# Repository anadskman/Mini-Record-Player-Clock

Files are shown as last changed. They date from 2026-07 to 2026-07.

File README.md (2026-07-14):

# Mini Record Player Clock

A compact desktop Bluetooth speaker and clock inspired by a vintage record player. The aim of this project is to combine a functional Bluetooth speaker and Wi-Fi clock into a clean, fully 3D printed desktop display. Rather than using lots of jumper wires and modules glued together, everything is connected through a custom PCB designed specifically for this project.

The record spins while music is playing, the tonearm moves using a servo, and the front display shows the current time synced over Wi-Fi. All electronics are housed inside a custom enclosure designed in Fusion 360.

## Features

- Bluetooth music playback
- Wi-Fi synced digital clock
- 2.4" ILI9341 colour TFT display
- Spinning 3D printed record
- Servo driven moving tonearm
- Physical playback buttons
- Custom PCB
- Fully 3D printed enclosure
- Powered by a 5V wall adapter

## Hardware

### Electronics

- ESP32 Dev Board
- 2.4" ILI9341 TFT Display
- PAM8403 Audio Amplifier
- 4Ω 3W Speaker
- 5V DC Motor
- SG90 Servo
- IRLZ44N MOSFET
- 1N5819 Diodes
- Push Buttons
- LEDs
- Capacitors and Resistors
- Custom PCB

### Mechanical

- Fully 3D printed enclosure
- 3D printed record
- 3D printed tonearm
- Motor mount
- Hinged lid
- PCB mounting system
- M2 hardware

## Software

The ESP32 is responsible for controlling the entire project. It handles Bluetooth audio, synchronises the clock over Wi-Fi, updates the display, controls the spinning record and tonearm, and reads the playback buttons.

The firmware is written using the Arduino framework and is designed so each part of the project works independently while sharing the same controller.

## PCB

A custom two-layer PCB was designed in KiCad to act as the hub of the project. All components connect directly to the PCB which keeps the wiring simple and makes assembly much cleaner.

Some design considerations included:

- Ground planes on both PCB layers
- Wider traces for power distribution
- Decoupling capacitors placed beside each module
- Reverse polarity protection
- Clearly labelled connectors
- Connectors for external buttons, speaker and servo
- Mounting holes for the enclosure

## CAD

The enclosure was designed in Fusion 360 around the PCB to ensure everything fits correctly.

The design includes:

- Front display opening
- Side mounted playback buttons
- Speaker openings
- Hinged top lid
- Motor mount
- Servo mount
- PCB mounting points
- Rear barrel jack opening

## BOM

| Component | Cost | Status |
|---|---:|---|
| TFT Display 2.4" ILI9341 | $4.01 | Buy |
| 4Ω 3W Speaker | $2.09 | Buy |
| Screw Terminal (7x) | Owned | Owned |
| DC Barrel Jack | Owned | Owned |
| LEDs (2x) | Owned | Owned |
| MOSFET | Owned | Owned |
| Header Pins | Owned | Owned |
| PAM8403 Amplifier Module | $4.02 | Buy |
| DC Motor | Owned | Owned |
| SG90 Servo Motor | Owned | Owned |
| 100µF Capacitors | Owned | Owned |
| 100nF Ceramic Capacitors | Owned | Owned |
| 470µF Capacitor | $8.65 | Buy |
| 10µF Capacitors | $2.13 | Buy |
| 1µF Capacitors | $2.08 | Buy |
| Resistors | Owned | Owned |
| 1N5819 Diodes | $4.35 | Buy |
| Push Buttons | Owned | Owned |
| ESP32 Dev Board | $4.40 | Buy |
| 5V 5A Barrel Jack Power Supply | $9.43 | Buy |
| PCB | $27.77 | Buy |
| M2 Screws | $5.40 | Buy |
| Pin Headers (ESP32) | $6.06 | Buy |
| Shipping | $1.63 | |
| Duties | $33.01 | |
| Total | $115.03 | |

## Images
| Schematic | PCB | CAD |
| :---: | :---: | :---: |
|  |  |  |

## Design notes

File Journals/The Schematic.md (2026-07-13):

# Schematic
***(3hr)***

I started by placing all the components *(Or their headers)*

#### ESP32
- `DEVKIT_V1_ESP32-WROOM-32`*(imported as the actual board wasnt on kicad)*

#### Power
- `DC Barrel Jack`*(I must make sure when choosing footprints I select a big enough holes for my barrel jack, my last one was too small)*
- x2 `PWR_FLAG` 
- `+5V` `GND`
- `Device:C_Polarized` *(470uF)*
- `Device:C` *(100nF)*
- `Device:C_Polarized` *(10uF)*
- `Switch:SW_SPST`
- `Diode:ss14`

#### Audio
- `Connector:Conn_01x09_Socket`
  - `Device:C` *(100nF)*
  - `Device:C_Polarized` *(10uF)*

#### Motor
- `Connector:Conn_01x02_Socket`
- `Transistor_FET:IRLZ44N`
- `Device:R` *(220R)*
- `Device:R` *(10K)*
- `1N5819`
- `Device:C_Polarized` *(100uF)*
- `Device:C` *(100nF)*

#### Speaker
- `Connector:Conn_01x02_Socket`

#### Servo
- `Connector:Conn_01x03_Pin`
- `Device:C_Polarized` *(100uF)*
- `Device:C` *(100nF)*

#### Display
- `Connector:Conn_01x14_Socket`
- x1 `Device:C` *(100nF)*
- `Device:C_Polarized` *(10uF)*

#### Buttons
- x3 `Switch:SW_Push`

#### LEDs
- x2 `Device:LED`
- x2 `Device:R` *(330R)*

#### Mounting holes
- x4 `Mechanical:MountingHole`

While I placing everything I added text to help keep everything tidy.



After I placed everything I did a quick sanity check and realised I forgot to add a few capacitors.

I started with all the power wiring first
I did wire the mosfet though, and the servo.

*(On my PCB I need to make sure my connectors line up, for e.g. gnd 5v and signal are in the correct place for servo)*



After those were wired I connected the Speaker to the audio amp, the LEDs to the esp32, and the Buttons to the esp32.

After they were connected I ran a quick ERC.



Before I moved on to the pcb I made sure everything was connected correctly, basically a sanity check, after that I also sent a Screenshot into #hardware to see if anyone spot anything wrong

Once everything seemed fine I annotated it and that was the schematic done.

I ended up change the buttons from being on the pcb, to be on the case instead so I replaced their footprints with `Connector_Generic:Conn_01x02`

I also found a symbol and footprint on github for pam8403 so i download it and replace my 01x09 connector with it.

# Footprints

After I annotated the schematic I assigned the footprints.

- `DEVKIT_V1_ESP32-WROOM-32:MODULE_DEVKIT_V1_ESP32-WROOM-32`
- `Connector_BarrelJack:BarrelJack_Horizontal` *(I measured my barrel Jack and made sure that it would fit)*
- `Connector_PinHeader_2.54mm:PinHeader_1x02_P2.54mm_Horizontal`
- `Capacitor_THT:CP_Radial_D5.0mm_P2.00mm`
- `Capacitor_THT:CP_Radial_D6.3mm_P2.50mm`
- `Capacitor_THT:CP_Radial_D8.0mm_P3.50mm`
*(I'll double check that my caps fit these footprints)*
- x2 `TerminalBlock_Phoenix:TerminalBlock_Phoenix_MPT-0,5-2-2.54_1x02_P2.54mm_Horizontal`
- `Connector_PinHeader_2.54mm:PinHeader_1x03_P2.54mm_Vertical`
- `Connector_PinHeader_2.54mm:PinHeader_1x14_P2.54mm_Vertical`
- `Package_TO_SOT_THT:TO-220-3_Vertical`
- `Resistor_THT:R_Axial_DIN0207_L6.3mm_D2.5mm_P10.16mm_Horizontal`



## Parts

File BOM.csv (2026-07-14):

Component | Cost | Status | Link
TFT Display 2.4" ILI9341 | $4.01 | Buy | https://www.aliexpress.com/item/1005006624846563.html
4Ω 3W Speaker | $2.09 | Buy | https://www.aliexpress.com/item/1005008004635189.html
Screw Terminal (7x) | Owned | Owned
DC Barrel Jack | Owned | Owned
LEDs (2x) | Owned | Owned
MOSFET | Owned | Owned
Header Pins | Owned | Owned
PAM8403 Amplifier Module | $4.02 | Buy | https://www.aliexpress.com/item/32848888092.html
DC Motor | Owned | Owned
SG90 Servo Motor | Owned | Owned
100µF Capacitors | Owned | Owned
100nF Ceramic Capacitors | Owned | Owned
470µF Capacitor | $8.65 | Buy | https://www.aliexpress.com/item/1005003808375884.html?pdp_ext_f=%7B"order"%3A"108"%2C"eval"%3A"1"%2C"fromPage"%3A"search"%7D
10µF Capacitors | $2.13 | Buy | https://www.aliexpress.com/item/1005011728628651.html
1µF Capacitors | $2.08 | Buy | https://www.aliexpress.com/item/1005011728628651.html
Resistors | Owned | Owned
1N5819 Diodes | $4.35 | Buy | https://www.aliexpress.com/item/32866531235.html
Push Buttons | Owned | Owned
ESP32 Dev Board | $4.40 | Buy | https://www.aliexpress.com/item/1005004605399313.html
5V 5A Barrel Jack Power Supply | $9.43 | Buy | https://www.aliexpress.com/item/1005009715118182.html?pdp_ext_f=%7B"order"%3A"274"%2C"eval"%3A"1"%2C"fromPage"%3A"search"%7D
PCB | $27.77 | Buy | https://jlcpcb.com
M2 Screws | $5.40 | Buy | https://www.aliexpress.com/item/1005011580506515.html?mp=1
Pin Headers (for ESP32) | $6.06 | Buy | https://www.aliexpress.com/item/1005004945845785.html?pdp_ext_f=%7B"order"%3A"238"%2C"spu_best_type"%3A"price"%2C"eval"%3A"1"%2C"fromPage"%3A"search"%7D
Shipping | $1.63 | Charge
Duties | $33.01 | Charge

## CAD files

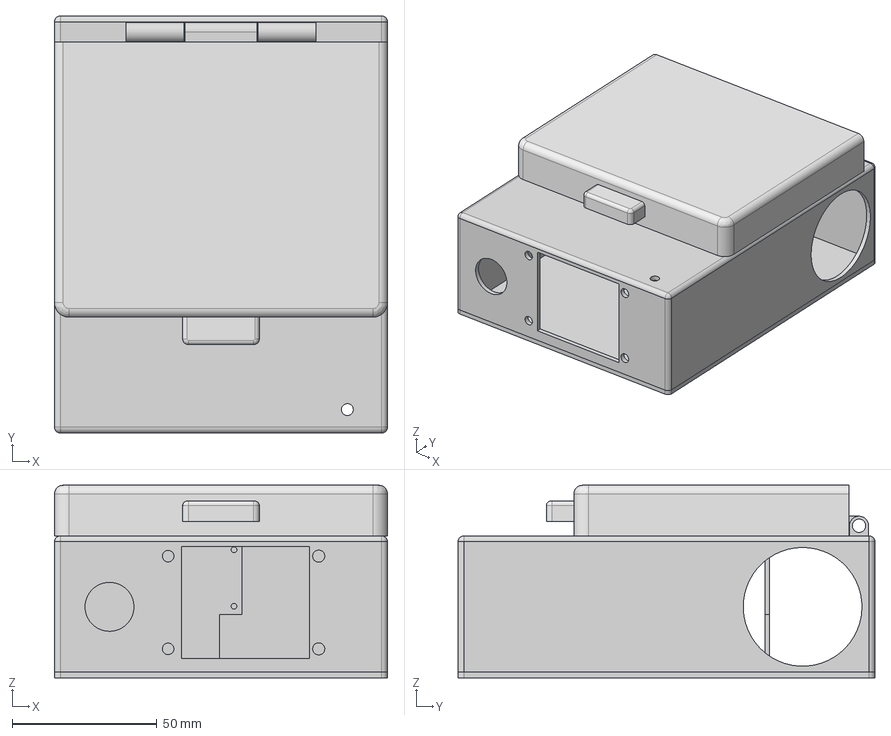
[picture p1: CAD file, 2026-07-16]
CAD/Record Player Clock - without components.step
115.0 x 144.0 x 66.5 mm
Front
Sides
Needle
Hinge
Back
Bottom

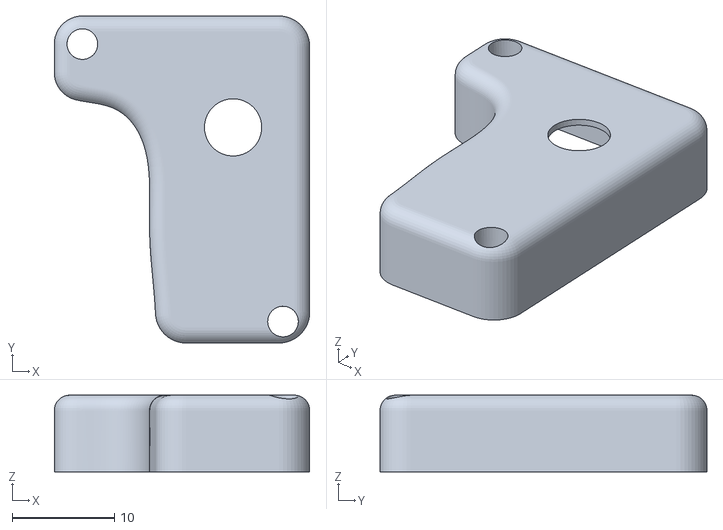
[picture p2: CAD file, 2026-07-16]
CAD/servo cover.stl
25.0 x 32.0 x 7.50

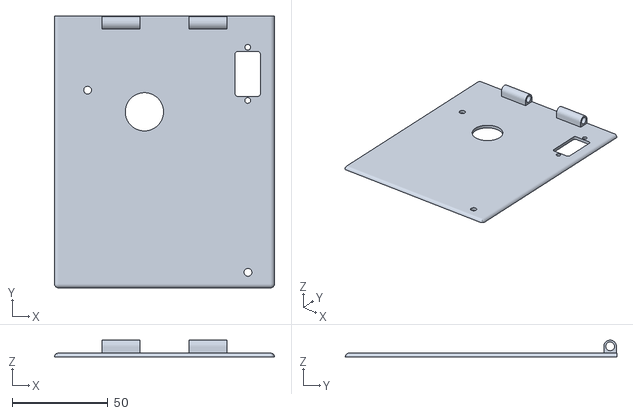
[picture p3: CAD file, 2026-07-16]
CAD/top.stl
115.0 x 142.0 x 8.80

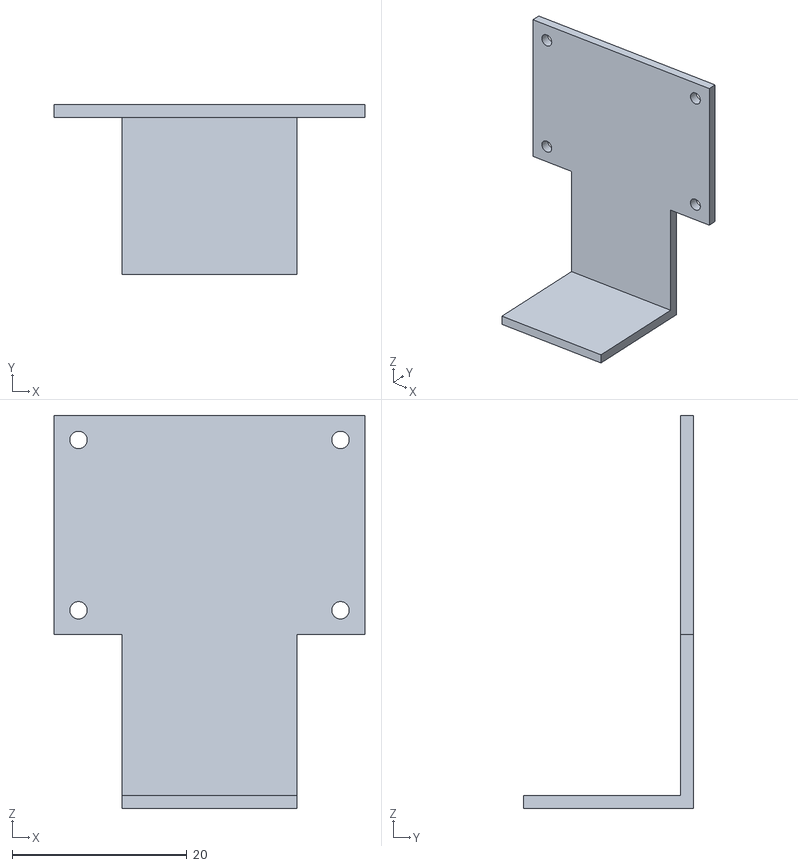
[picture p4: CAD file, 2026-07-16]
CAD/motor mount.stl
35.6 x 19.5 x 45.0

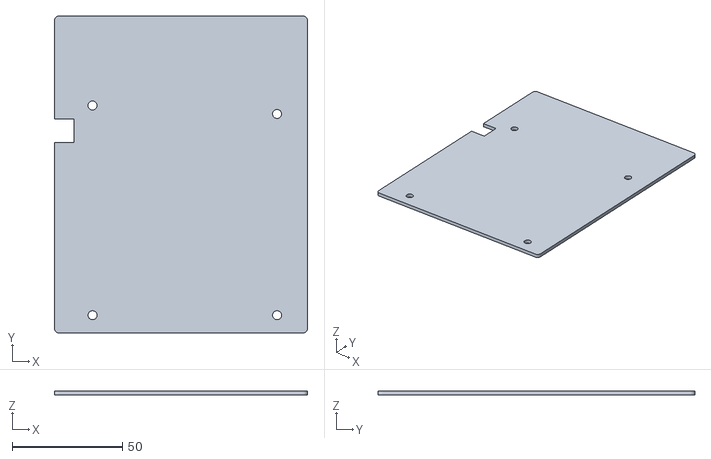
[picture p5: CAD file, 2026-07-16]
CAD/bottom.stl
115.0 x 144.0 x 2.00

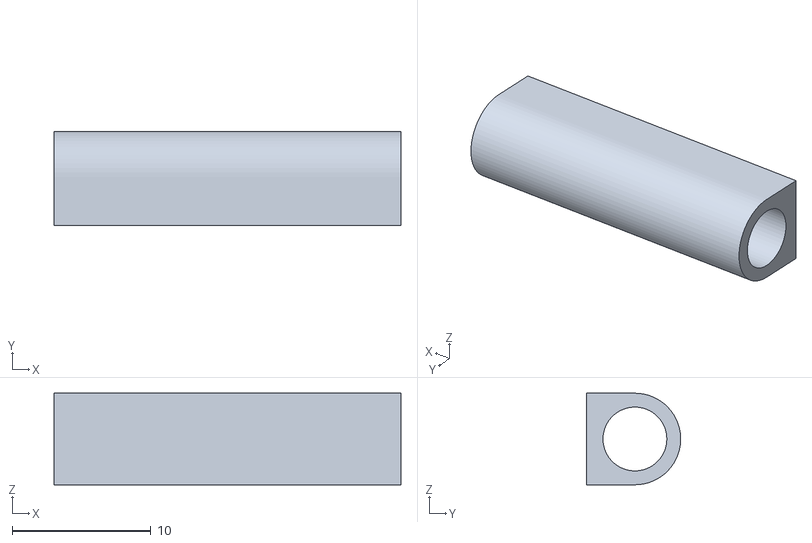
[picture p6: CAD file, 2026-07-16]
CAD/Hinge for lid.stl
25.0 x 6.80 x 6.60

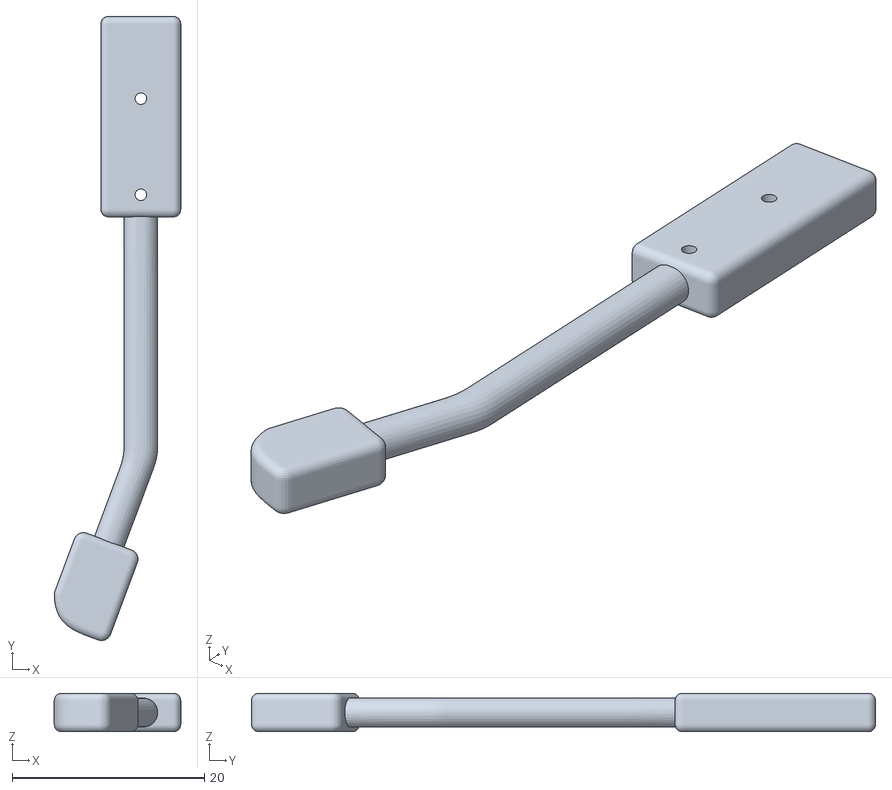
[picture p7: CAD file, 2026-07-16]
CAD/needle.stl
13.2 x 64.9 x 4.00

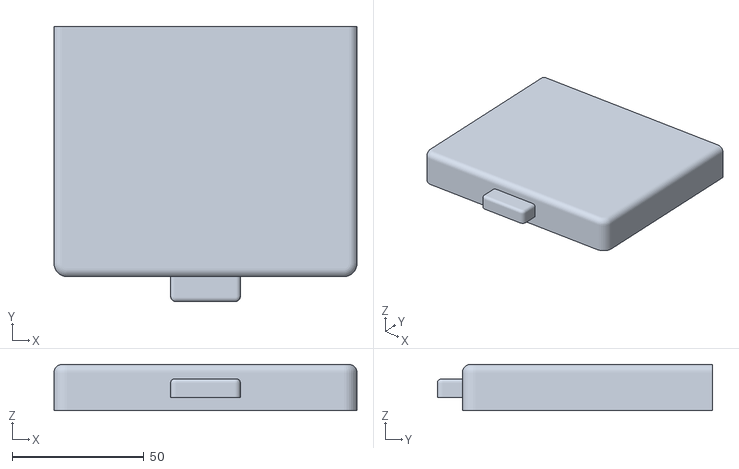
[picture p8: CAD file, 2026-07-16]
CAD/Lid.stl
115.0 x 104.5 x 17.5

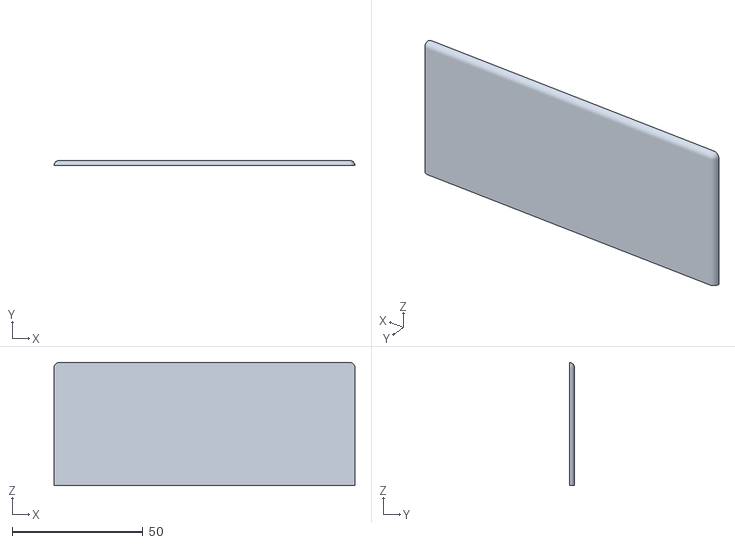
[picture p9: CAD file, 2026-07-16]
CAD/back.stl
115.0 x 2.00 x 47.0

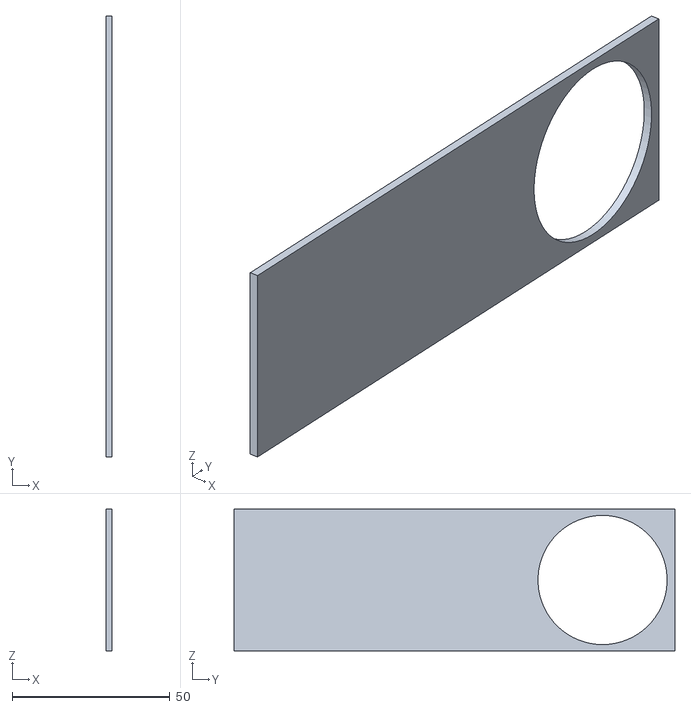
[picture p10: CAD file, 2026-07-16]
CAD/right.stl
2.00 x 140.0 x 45.0

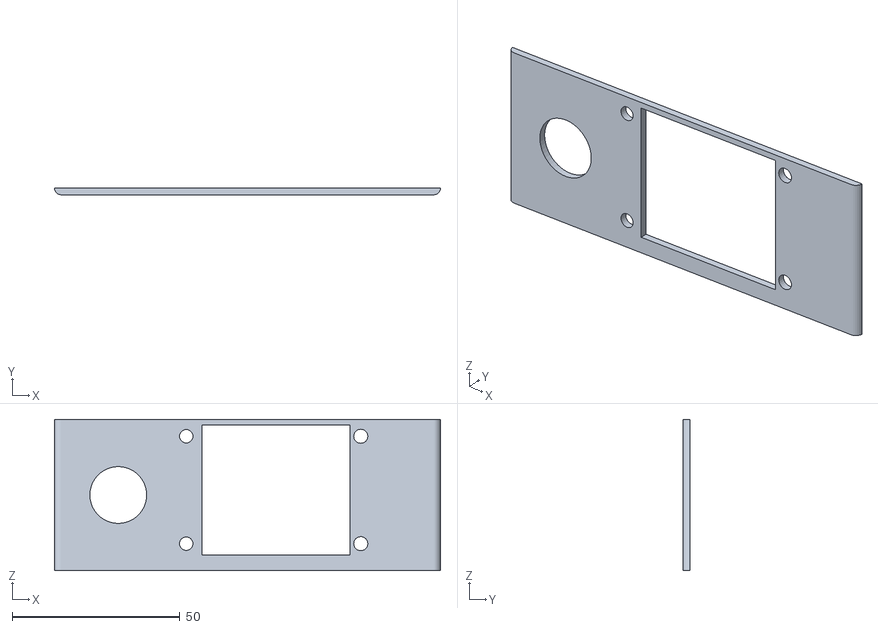
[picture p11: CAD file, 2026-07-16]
CAD/front.stl
115.0 x 2.00 x 45.0

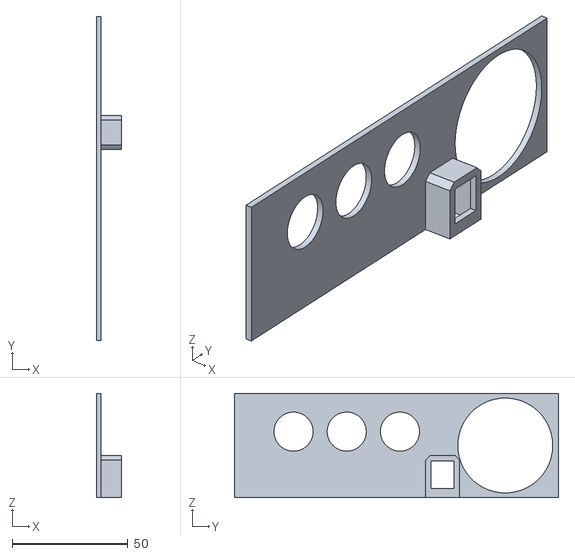
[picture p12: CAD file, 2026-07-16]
CAD/left.stl
11.0 x 140.0 x 45.0

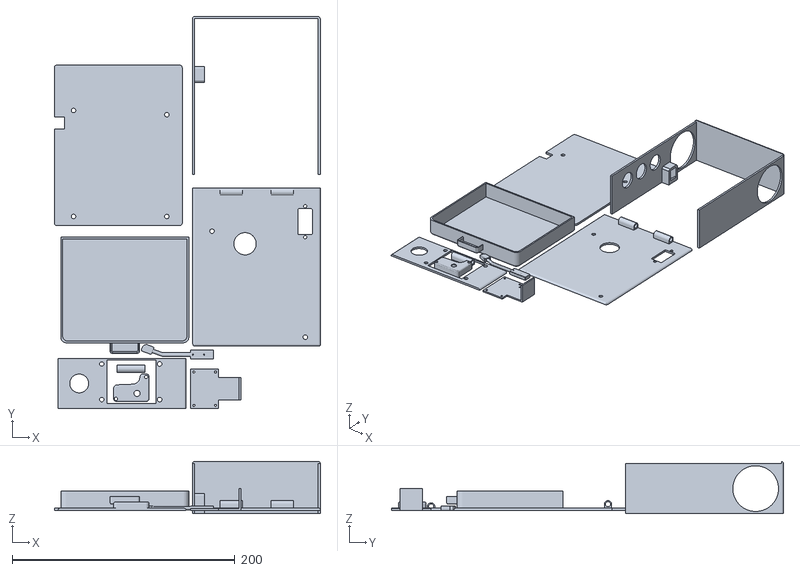
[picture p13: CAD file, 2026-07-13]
CAD/Mini Record Player Clock - Printable.stl
239.4 x 352.2 x 47.0

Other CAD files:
CAD/Mini Record-Player-PCB.step

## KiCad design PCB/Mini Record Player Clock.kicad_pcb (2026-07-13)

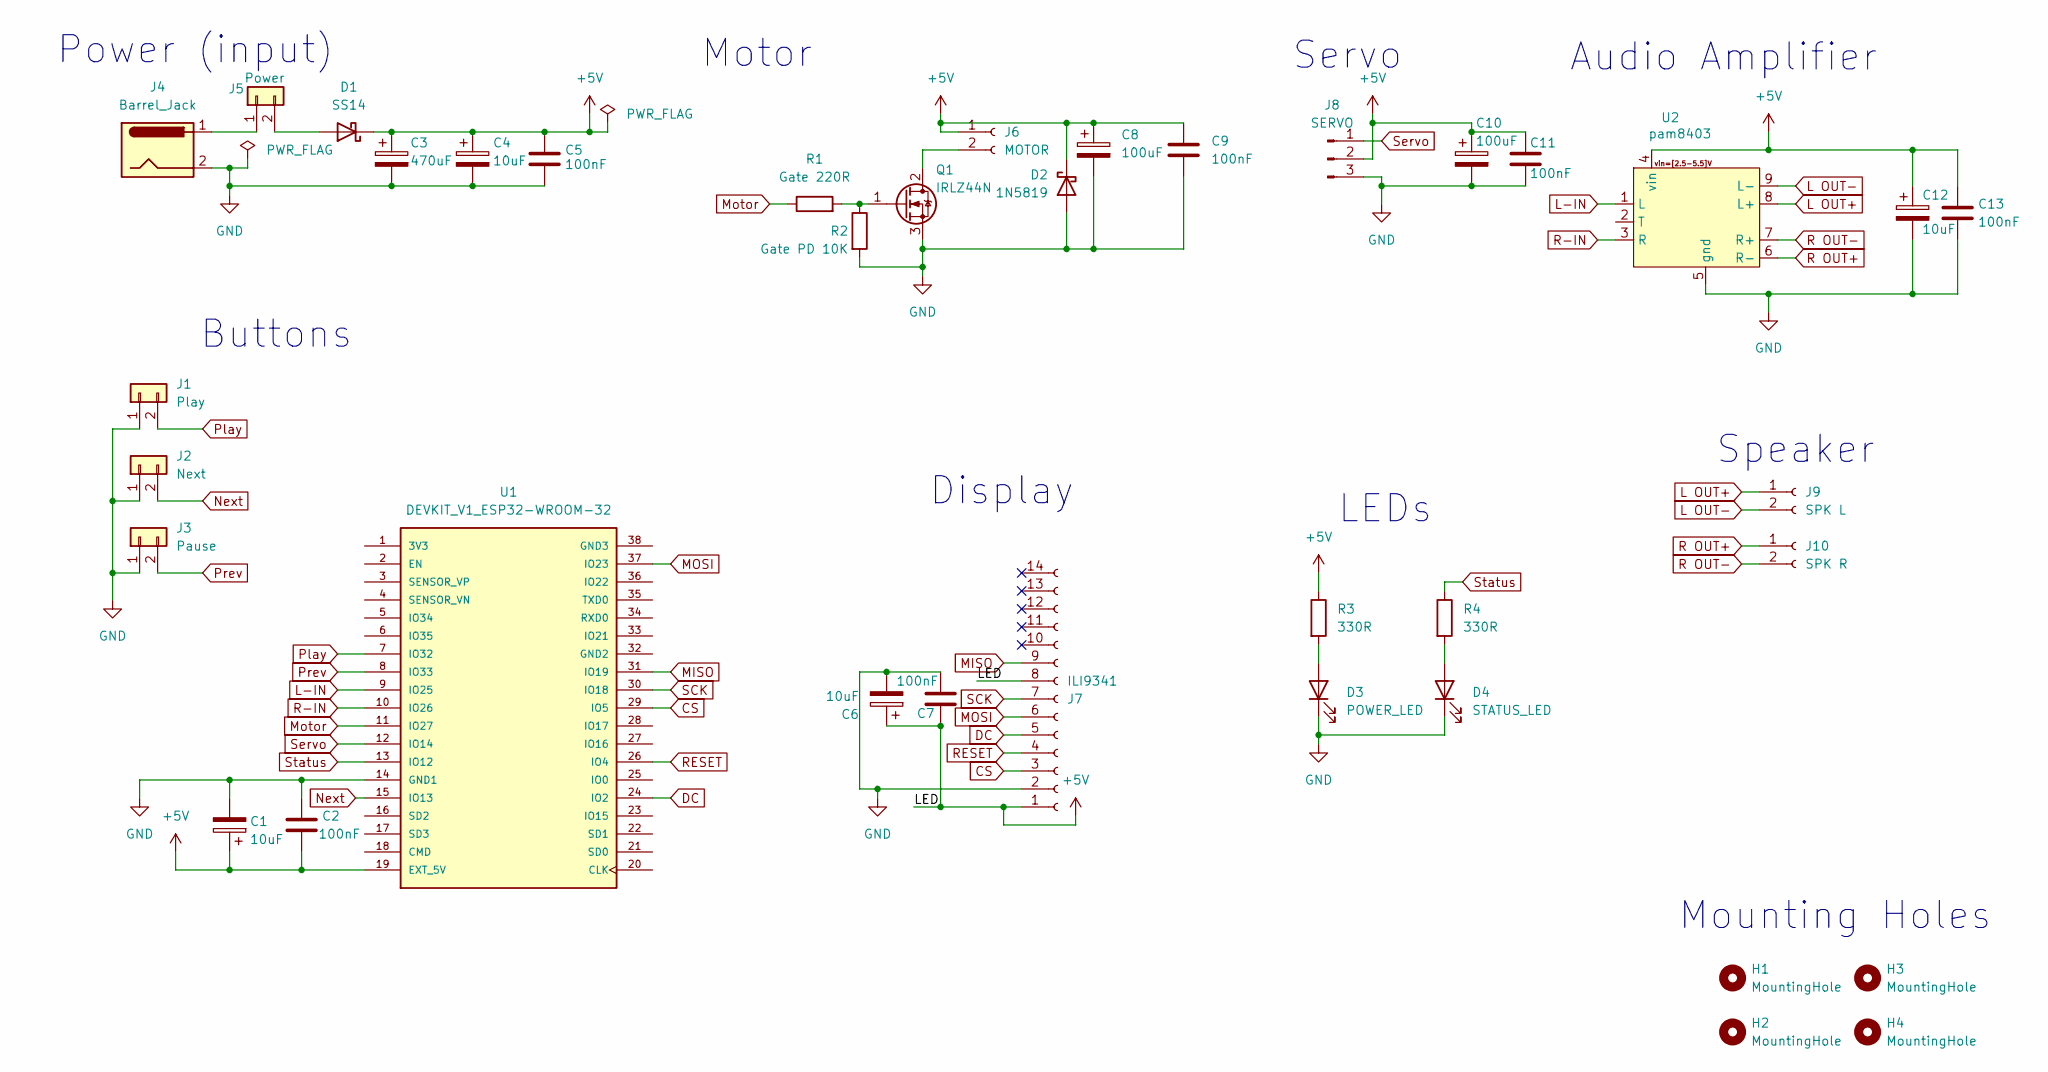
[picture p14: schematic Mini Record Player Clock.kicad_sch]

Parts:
C1, C4, C6, C12: 10uF; CP_Radial_D5.0mm_P2.00mm
C2, C5, C7, C9, C11, C13: 100nF; C_Disc_D5.0mm_W2.5mm_P5.00mm
C3: 470uF; CP_Radial_D8.0mm_P3.50mm
C8, C10: 100uF; CP_Radial_D6.3mm_P2.50mm
D1: SS14; D_DO-41_SOD81_P10.16mm_Horizontal
D2: 1N5819; D_DO-41_SOD81_P10.16mm_Horizontal
D3: POWER_LED; LED_D5.0mm
D4: STATUS_LED; LED_D5.0mm
H1, H2, H3, H4: MountingHole; MountingHole_3.2mm_M3
J1: Play; TerminalBlock_Phoenix_MPT-0,5-2-2.54_1x02_P2.54mm_Horizontal
J2: Next; TerminalBlock_Phoenix_MPT-0,5-2-2.54_1x02_P2.54mm_Horizontal
J3: Pause; TerminalBlock_Phoenix_MPT-0,5-2-2.54_1x02_P2.54mm_Horizontal
J4: Barrel_Jack; BarrelJack_Horizontal
J5: Power; TerminalBlock_Phoenix_MPT-0,5-2-2.54_1x02_P2.54mm_Horizontal
J6: MOTOR; TerminalBlock_Phoenix_MPT-0,5-2-2.54_1x02_P2.54mm_Horizontal
J7: ILI9341; PinHeader_1x14_P2.54mm_Vertical
J8: SERVO; PinHeader_1x03_P2.54mm_Vertical
J9: SPK L; TerminalBlock_Phoenix_MPT-0,5-2-2.54_1x02_P2.54mm_Horizontal
J10: SPK R; TerminalBlock_Phoenix_MPT-0,5-2-2.54_1x02_P2.54mm_Horizontal
Q1: IRLZ44N; TO-220-3_Vertical
R1: Gate 220R; R_Axial_DIN0207_L6.3mm_D2.5mm_P10.16mm_Horizontal
R2: Gate PD 10K; R_Axial_DIN0207_L6.3mm_D2.5mm_P10.16mm_Horizontal
R3, R4: 330R; R_Axial_DIN0207_L6.3mm_D2.5mm_P10.16mm_Horizontal
U1: DEVKIT_V1_ESP32-WROOM-32; MODULE_DEVKIT_V1_ESP32-WROOM-32; PARTREV N/A
U2: pam8403

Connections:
+5V: C1.1, C2.2, C3.1, C4.1, C5.1, C6.1, C7.1, C8.1, C9.1, C10.1, C11.1, C12.1, C13.1, D1.1 (K), D2.1 (K), J6.1, J7.1, J7.8, J8.2, R3.1, U1.19 (EXT_5V), U2.4 (vin)
CS: J7.3, U1.29 (IO5)
DC: J7.5, U1.24 (IO2)
GND: C1.2, C2.1, C3.2, C4.2, C5.2, C6.2, C7.2, C8.2, C9.2, C10.2, C11.2, C12.2, C13.2, D2.2 (A), D3.1 (K), D4.1 (K), J1.1, J2.1, J3.1, J4.2, J7.2, J8.3, Q1.3 (S), R2.2, U1.14 (GND1), U2.5 (gnd)
L OUT+: J9.1, U2.8 (L+)
L OUT-: J9.2, U2.9 (L-)
L-IN: U1.9 (IO25), U2.1 (L)
MISO: J7.9, U1.31 (IO19)
MOSI: J7.6, U1.37 (IO23)
Motor: R1.1, U1.11 (IO27)
unnamed: D1.2 (A), J5.2
unnamed: D3.2 (A), R3.2
unnamed: D4.2 (A), R4.2
unnamed: J4.1, J5.1
unnamed: J6.2, Q1.2 (D)
unnamed: Q1.1 (G), R1.2, R2.1
Next: J2.2, U1.15 (IO13)
Play: J1.2, U1.7 (IO32)
Prev: J3.2, U1.8 (IO33)
R OUT+: J10.1, U2.6 (R-)
R OUT-: J10.2, U2.7 (R+)
R-IN: U1.10 (IO26), U2.3 (R)
RESET: J7.4, U1.26 (IO4)
SCK: J7.7, U1.30 (IO18)
Servo: J8.1, U1.12 (IO14)
Status: R4.1, U1.13 (IO12)

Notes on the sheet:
Display
Mounting Holes
Audio Amplifier
LEDs
Speaker
Power (input)
Motor
Buttons
Servo

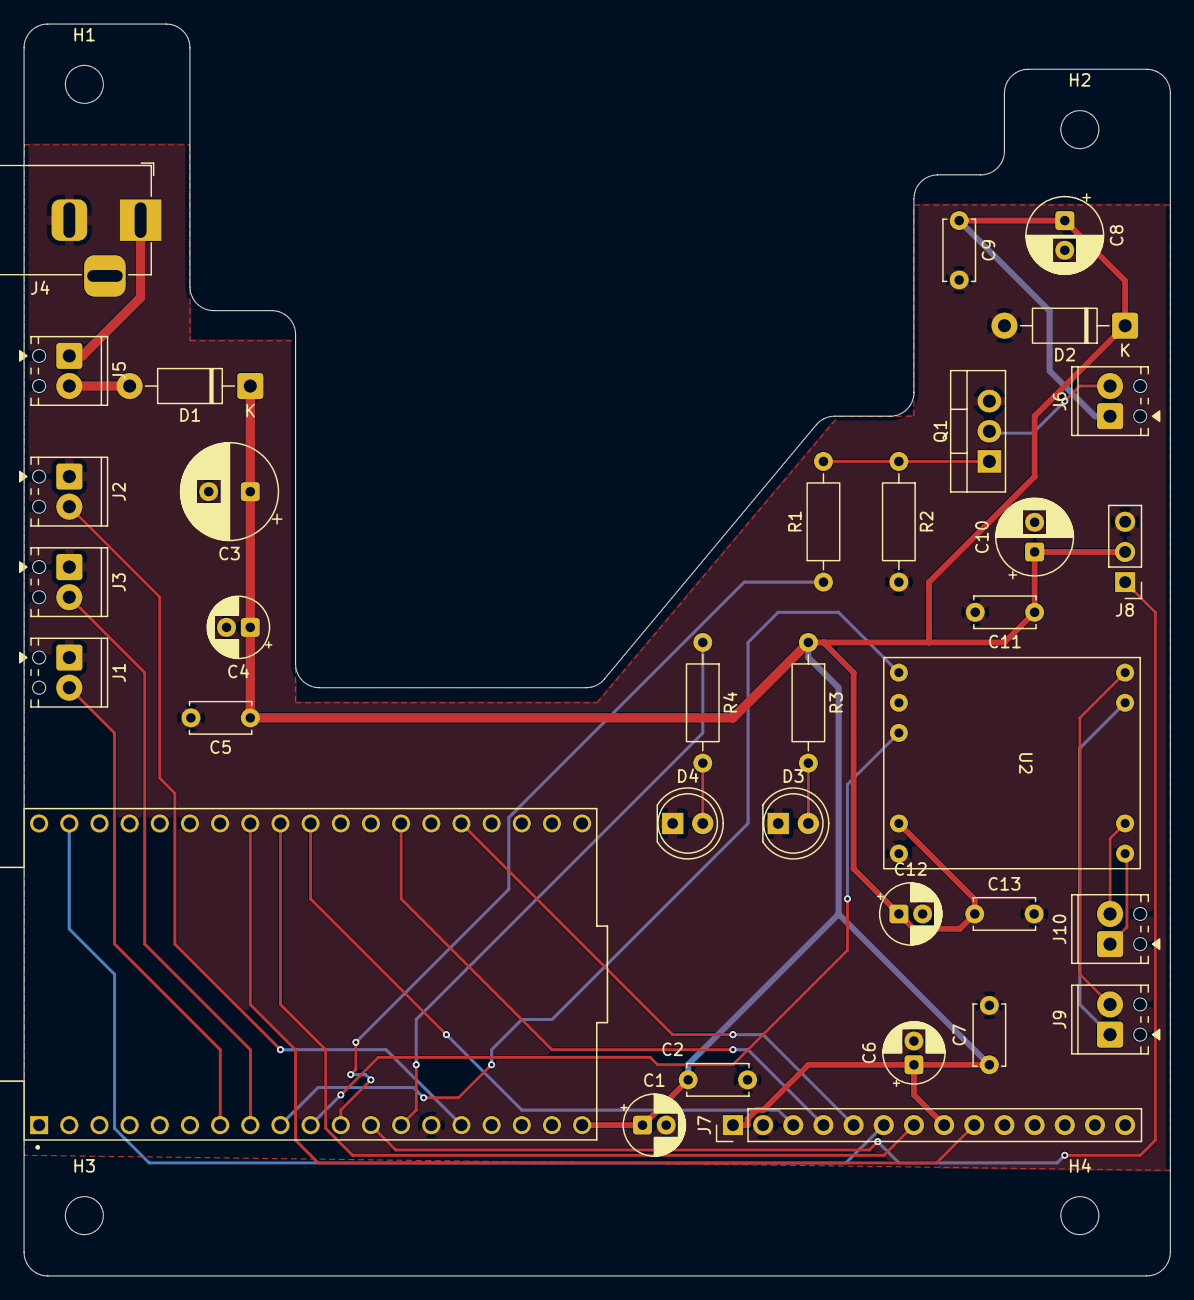
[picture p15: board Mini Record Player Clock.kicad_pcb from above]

Board: 2 copper layers, 96.5 x 105.4 mm, 38 parts (0 on the bottom side), 26 nets.

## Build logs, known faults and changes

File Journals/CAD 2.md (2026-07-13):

# CAD 2
***(2:30hr)***

I started with the top cover so inside of `Top` I made a new component called `Lid`
and I made sketch on the flat top part of the case and sketched out where I want the lid to cover and extruded it out.

Im hoping 1.5mm walls will be thick enough to not break but still print quick.
On the back of the lid I allowed extra room for the hinge.

Then I made another component inside `Lid` called `Hinge` and of course, made the hinge. I made it similar to a door hinge, you just have to put a nail or rod through the holes.

Afterwards, I made another component `Back` and created a simple back on it.

I did the same for `Bottom`, but I added holes for mounting to the pcb.
I extrude 2 out of 4 of the holes to the top aswell *(I have 40mm copper pillars i can put to hold it up)*

After that I added holes to attach my motor mount to. 

************SCreensHOT************

So with that the cad is done.

************SCreensHOT************

Lastly I laid everything out the be 3d printed and exported it.

Then I Made my bom and github.

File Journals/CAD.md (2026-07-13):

# CAD
***(4:15hr)***

I started by Setting up my workspace, I created a component called `PCB` and imported my pcb.step into it.

Then I created another component called `Front` and uploaded a model of the display.

Then I used that model to "Trace" where it would go and extruded the front plane.

Afterwards I create a near scale of my actual buttons and put it inside a component inside `Front`, I called it `Button`.

Then I put it where I wanted it to go and cut that into the front body,
so with that the front should be complete.

***************ScreenSHOT***************

I made a new component `Sides`
This is where the speakers will be and the play, prev, next buttons.

I made a sketch on the left wall and projected the barrel jack out and then cut it out.
On the same wall I cut out 3 circles for the 3 buttons too.

I moved the pcb to the right a little bit to give the buttons some space.
I also adjusted the cutout for the barrel jack by pushing the wall back on that area.

Then I just extruded the other wall 115mm aswell.
I made a new component called `Speaker` and made a 40m diameter x 5mm circle *(thats what the aliexpress item has)*.
I actually forgot to allow room for a speaker on the Left, so to fix it I just extrude the walls down further, so they were 140mm.

Then I cut out the speaker holes on both sides

***************ScreenSHOT***************

The next component I made was `Top`.

I started by making a big 80mm circle *(This will be the record)* and a 2mm hole in the middle of it of the motor.
From the same center point I made another circle 20mm diameter, this will let the motor stick out a little bit.

Next thing I did was sketch out the needle arm bit which connects to the servo, now for this part I did take inspiration from the "reference" image I had in my first journal log.

I started by adding a model of a servo and start marking around it.

I extruded the whole top piece and then made a new component `Disc` and extruded... The disc of course.

I made a quick model of my motor and put it into place

Afterwards I made a cover to go over the servo hiding it, I added to holes for it to be screwed into the top.

Then I made a new component inside `Top` called `Needle`.
From there I designed the needle and ensured to make it screwable to the servo horn.

I test it to see that it would reach the disc properly and it does.

Now thats about half the top done.

***************ScreenSHOT***************

**Next up**
- Motor mount *(I have a mount I just need to make it connectable to the case)*
- Lid for top *(I have some clear petg ill try to use)*
- Hinge for mount *(Ill just do the same color as rest of case instead of clear, I think itll look nicer)*
- bottom
- revise how everything connects
- sanity check

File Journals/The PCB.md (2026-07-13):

# PCB
***(2hr)***

## Placing Footprints

I started by setting my grid to 50 mils.
I also set my trace sizes:

- Logic .25mm
- +5V to esp/display .4mm
- +5V to Pam8403/Servo/Motor .5mm
- Main +5V from barrel jack .8mm

For GND Ill be using a ground plane

Before placing the ILI9341 I fixed the Schematic of it, labeling each pin in order.
Then I placed it at the bottom of the PCB

I also fixed the servos pin order

I made sure to keep each section together and the caps near their components power pins.

Once I had all my components placed I Started routing



## Routing

I started with the +5V rails, using .8mm from barrel jack to power led, and then branching from the power led to everything else.

To make thing as easy as possible I highlighted the +5V Net.

After 5v routed the button's logic, I swap the placement i orginally had for the buttons because the pins are place the other way round so it would mean using vias when theres a work around.

Everything else is pretty simple, not really anything to journal about.
Unless I write everything, I mean everything, R-In dx151.13 dx 133.35.
But no, I wont be doing that.

Once I routed everything I ran a quick DRC, and beside unconnect GNDs *(I didnt make copper plate yet)* it was all fine.

So then I made the edge cuts around the Mounting Holes and made the copper plate,
I also put fillets on every corner to make it all look that bit nicer.
Lastly I ran one last DRC and... 
2 Errors, unconnect gnds.

Thats because I forgot to let the copper plate run on B.cu aswell, ran DRC again; only 1 error about thermal, moved a few traces and...
0 Errors!!

So with that, the PCB is DONE!!!!!!



Last thing I did was get 3d model of esp and audio amp module and upload them, then export the .step



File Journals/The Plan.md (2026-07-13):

# The Plan
***(15min)***

## Goal

Build a compact desktop Bluetooth speaker and clock inspired by a vintage record player. The device will feature a spinning record, moving tonearm, colour display, Bluetooth audio, and physical controls. It will use a custom PCB to minimise wiring and create a clean design.

## Features
- Bluetooth audio playback
- Digital clock with Wi-Fi time sync
- 2.4" colour TFT display
- Spinning record animation
- Moving tonearm
- Physical playback buttons
- 3D printed enclosure
- Custom PCB
- Powered by a 5V wall adapter

## Electronics
- ESP32-WROOM-32
- 2.4" ILI9341 SPI TFT Display
- PAM8403 Audio Amplifier
- 4Ω 3W Speaker
- 5V DC Motor
- IRLZ44N MOSFET
- SG90 Servo
- 4× Push Buttons
- 5.5×2.1mm Barrel Jack
- On/Off Switch
- Power LED
- Status LED

## Passive Components
- 220Ω Resistor
- 10kΩ Resistor
- 100nF Capacitors
- 10µF Capacitors
- 100µF Capacitors
- 470µF Capacitor
- 1N5819 (or SS14) Flyback Diode

## Mechanical
- Custom PCB
- 3D Printed Enclosure
- 3D Printed Turntable
- 3D Printed Record
- 3D Printed Tonearm
- 608 Bearing
- M2/M3 Hardware

## PCB Purpose
The PCB is the main "hub" of the project, all components leading back to it.

### Core Requirements
- Single custom PCB for all electronics
- Powered from a 5V DC barrel jack
- Common ground plane for all components
- Clearly labelled connectors and test points
- Compact layout to fit inside the enclosure

## Functional Requirements

### Microcontroller
- ESP32-WROOM-32
- Wi-Fi antenna kept free from copper and components

### Display
- Header for 2.4" ILI9341 SPI TFT display
- Backlight power connection
- SPI traces kept short where practical

### Audio
- PAM8403 amplifier integrated on the PCB
- Speaker output connector
- Audio traces routed away from motor wiring to reduce noise

### Motor Control
- IRLZ44N MOSFET
- Flyback diode
- PWM control from ESP32
- Motor connector

### Servo
- 3-pin servo header (5V, GND, Signal)
#### User Controls
- Headers or footprints for:
 - Play/Pause
 - Previous
 - Next
 - power
- status LED
- Power LED

### Power
- 5V barrel jack input
- Power switch
- Reverse polarity protection
- Decoupling capacitors near all ICs
- Large bulk capacitor on the 5V rail

### PCB Design Goals
- Two-layer PCB
- Large ground plane on both layers
- Wide traces for motor, amplifier, and power
- Separate high-current and signal routing where possible
- Mounting holes for enclosure
- JST or pin-header connectors for removable components
- Silkscreen labels for every connector and pin

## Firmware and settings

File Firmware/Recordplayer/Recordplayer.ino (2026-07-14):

#include <WiFi.h>
#include <time.h>
#include <SPI.h>
#include <Adafruit_GFX.h>
#include <Adafruit_ILI9341.h>
#include <ESP32Servo.h>

const char* ssid = "WIFI";
const char* password = "PASSWORD";

const char* ntpServer = "pool.ntp.org";
const long gmtOffset_sec = 0;
const int daylightOffset_sec = 3600;

#define TFT_CS     5
#define TFT_DC     2
#define TFT_RST    4

#define MOTOR_PIN  27
#define SERVO_PIN  14

#define BTN_PLAY   32
#define BTN_PREV   33
#define BTN_NEXT   13

#define STATUS_LED 12


Adafruit_ILI9341 tft(TFT_CS, TFT_DC, TFT_RST);
Servo tonearm;


bool playing = false;


void connectWiFi()
{
    WiFi.begin(ssid, password);

    while (WiFi.status() != WL_CONNECTED)
    {
        delay(500);
    }

    configTime(gmtOffset_sec, daylightOffset_sec, ntpServer);
}


void drawClock()
{
    struct tm timeinfo;

    if (!getLocalTime(&timeinfo))
        return;

    char buffer[10];

    strftime(buffer, sizeof(buffer), "%H:%M", &timeinfo);

    tft.fillRect(0, 0, 240, 50, ILI9341_BLACK);

    tft.setCursor(20, 10);
    tft.setTextColor(ILI9341_WHITE);
    tft.setTextSize(4);
    tft.print(buffer);
}


void updateMotor()
{
    if (playing)
        analogWrite(MOTOR_PIN, 180);
    else
        analogWrite(MOTOR_PIN, 0);
}


void updateServo()
{
    if (playing)
        tonearm.write(45);
    else
        tonearm.write(0);
}


void checkButtons()
{
    static bool lastPlay = HIGH;

    bool play = digitalRead(BTN_PLAY);

    if (lastPlay == HIGH && play == LOW)
    {
        playing = !playing;

        updateMotor();
        updateServo();
    }

    lastPlay = play;

    // Previous
    if (digitalRead(BTN_PREV) == LOW)
    {
    }

    // Next
    if (digitalRead(BTN_NEXT) == LOW)
    {
    }
}


void setup()
{
    Serial.begin(115200);

    pinMode(MOTOR_PIN, OUTPUT);

    pinMode(BTN_PLAY, INPUT_PULLUP);
    pinMode(BTN_PREV, INPUT_PULLUP);
    pinMode(BTN_NEXT, INPUT_PULLUP);

    pinMode(STATUS_LED, OUTPUT);

    digitalWrite(STATUS_LED, LOW);

    tonearm.attach(SERVO_PIN);

    tft.begin();
    tft.setRotation(1);
    tft.fillScreen(ILI9341_BLACK);

    connectWiFi();

    updateMotor();
    updateServo();
}

void loop()
{
    drawClock();

    checkButtons();

    digitalWrite(STATUS_LED, WiFi.status() == WL_CONNECTED);

    delay(100);
}

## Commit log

2026-07-13 Files upload
    [Mini Record Player Clock - Printable.stl, Mini Record Player Clock.kicad_pcb, Mini Record Player Clock.kicad_sch]
2026-07-13 Add Bill of Materials (BOM) CSV file
    [BOM.csv]
2026-07-13 Expand README with project details and images
    Added detailed project description, features, hardware, software, PCB design considerations, CAD design, BOM, and images.
2026-07-16 stl files
    [Hinge for lid.stl, Lid.stl, back.stl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]
2026-07-16 Create Record Player Clock - without components.step
    [Record Player Clock - without components.step]
2026-07-16 Rename Mini Record-Player.step to Mini Record-Player-PCB.step
    [Mini Record-Player-PCB.step]
